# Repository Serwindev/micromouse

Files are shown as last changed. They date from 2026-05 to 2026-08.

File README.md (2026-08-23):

# Project Zacch v1

## About the project

Project Zacch is a full-size micromouse whose aim is to solve the maze autonomously.

The name of the mouse actually comes from Bible (Luke 19:1-10). There was a man called Zacchaeus -- who wanted to see Jesus but because he was short, he couldn't able to see Him. So he climbed a tree to see Jesus.

The dimension of Zacch is 90mm x 127mm (3.54 x 5.00 inches). Compared to other mice out there, it isn't that small. But this is my first-ever hardware project and i needed some more space to work properly.

The Project Zacch v1 is a project made for the event ["Fallout"](https://fallout.hackclub.com/) conducted by [HackClub](https://hackclub.com/).

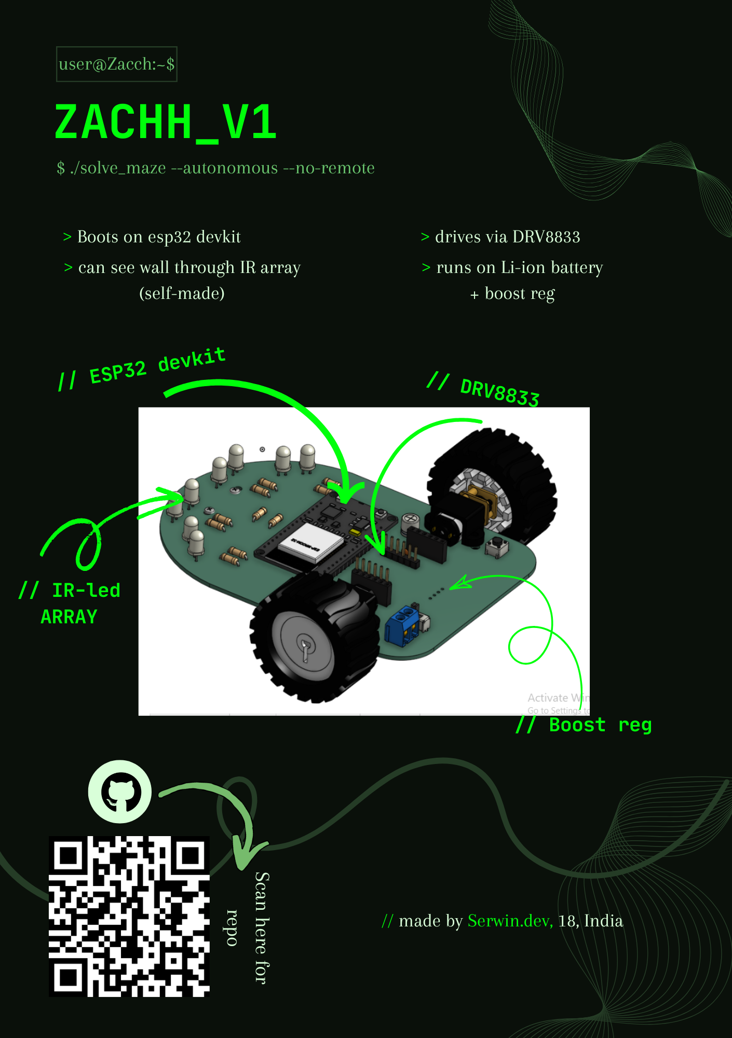
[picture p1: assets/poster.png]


---

## BOM

|sno|product name |description |Quantity |link |unit price |amount |Running total | |
|---|---|---|---|---|---|---|---|---|
|  1| ESP32 | Brain of the Mouse | 1| [link](https://makerbazar.in/products/esp32-wroom-wifi-ble-bluetooth-iot-node-mcu-board?variant=48251049935088) | 445.00| 445.00| 445 | |
|  2| Motor Driver | Bridge between Brain and motor | 1| [link](https://makerbazar.in/products/drv8833-2-channel-1-5a-dc-motor-driver?variant=48341841346800) | 65.00|  65.00| 510 | |
|  3| Motors with encoders| Locomotive device to calculate it's position| 2| [link](https://roboticsdna.in/product/n20-6v-500rpm-micro-metal-gear-motor-with-encoder/ ) | 494 | 988 | 1498 | |
|  4| Infrared Sensors | Eyes to watch out for obstacles | 2| [link](https://makerbazar.in/products/ir-receiver-transistor-led?variant=42847315525872) | 99.00| 198 | 1696 | |
|  5| Battery | To power the mouse | 1| [link](https://robu.in/product/wly603040-600mah-3-7v-single-cell-rechargeable-lipo-battery/?utm_source=chatgpt.com) | 198 | 198 | 1894 | |
|  6| MOSFET | To switch on the IR leds | 2| [link](https://www.digikey.in/en/products/detail/alpha-omega-semiconductor-inc/AO3400A/1855772) | 49.15|  98.30| 1992.3 | |
|  7| Resistors pack | TO limit the current | 1| [link](https://robu.in/product/30-different-valued-metal-film-resistor-assorted-kit-for-diy-electronic-projects-and-experiments/) | 199.00| 199.00| 2191.3 | |
|  8| Wheels | Pair of wheels suitable for N20 | 1| [link](https://dyoraarobotics.in/product/2) | 269 | 269 | 2460.3 | |
|  9| Caster ball | Non-driven wheel to support the mouse | 1| [link](https://makerbazar.in/products/mini-3pi-car-n20-caster-robot-ball-wheel) | 39 |  39 | 2499.3 | |
| 10| Boost converter | To convert low voltage into 5v | 1| [link](https://robocraze.com/products/tps61023-3-7a-5v-output-mini-boost-converter-breakout-board-7semi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) | 87 |  87 | 2586.3 | |
| 11| Switch | To power ON/OFF | 1| [link](https://makerbazar.in/products/3-pin-dip-mini-slide-switch-through-hole-pcb-slide-button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) | 55 |  55 | 2641.3 | |
| 12| Screw terminal | To connect battery | 1| [link](https://makerbazar.in/products/wire-to-board-screw-terminal-connectors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) | 25 |  25 | 2666.3 | |
| 13| Capacitor 47uF | Caps to store energy | 3| [link](https://www.mouser.in/en/ProductDetail/Panasonic/ECA-1HHG470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) | 17.89|  53.67| 2719.97| |
| 14| Capacitor 0.1uF | Caps | 10| [link](https://robu.in/product/rder71h104k0m1h03a-murata-electronics-%C2%B110-50v-100nf-x7r-pluginp5mm-multilayer-ceramic-capacitors-mlcc-leaded-rohs/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) | 16.00| 160 | 2879.97| |
| 15| Female headers | To mount componenets | 3| [link](https://makerbazar.in/products/female-berg-strip-2-54mm-header-pin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)| 8.5 |  25.50| 2905.47| |
| 16| Male headers | To mount components | 2| [link](https://makerbazar.in/products/berg-strip-40-pins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) | 25 |  50 | 2955.47| |
| 17| Tactile switch | To actually make mouse move | 1| [link](https://makerbazar.in/products/small-push-button-switch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) | 20 |  20 | 2975.47| |
| 18  | PCB | Acts as a chassis as well as electrical circuit | 1 | wherever you prefer | 3500 | 3500 | 6475.47 | |
| 19  | 3d print | Mounts for motors | 2 | wherever you prefer (use assets/CAD_design/Motot_mount.stp) | 500 | 1000 | 7475.47 | |

---

## Project Workflow

I have actually journalled everything from Day 1 till the end -- you can find them in the **Devlogs folder**.

#### Research and Development

- On the Day 1, i worked on researching the requirments for the project.
- On further days, i sourced online to find the suitable products and built the BOM (Bill of materials) -- which you can find [here](components/BOM.csv) and also sketched a very rough diagram about the wiring.

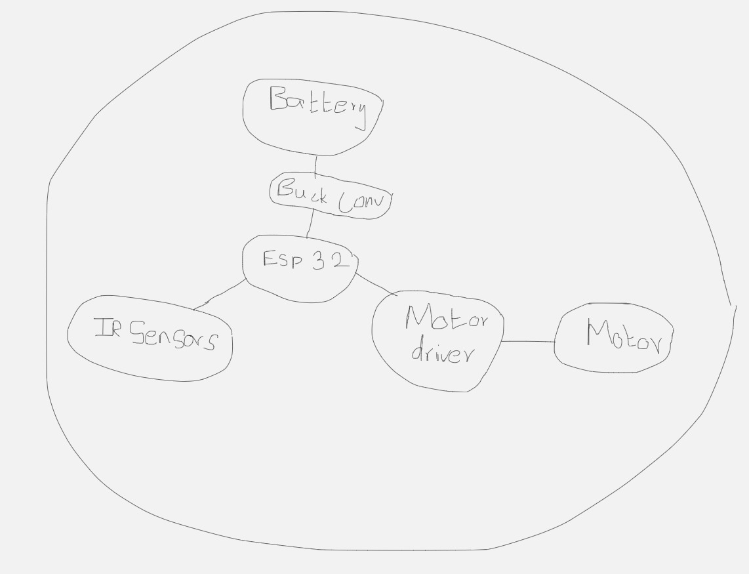
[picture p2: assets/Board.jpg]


---

#### Schematic 

- From day 4, i worked on the Schematic design in Kicad. It's my very first time and i found it kinda hard at first.
- After some several iterations and struggles, with the help of chatGPT, i finished the 1st version of schematic on day 7

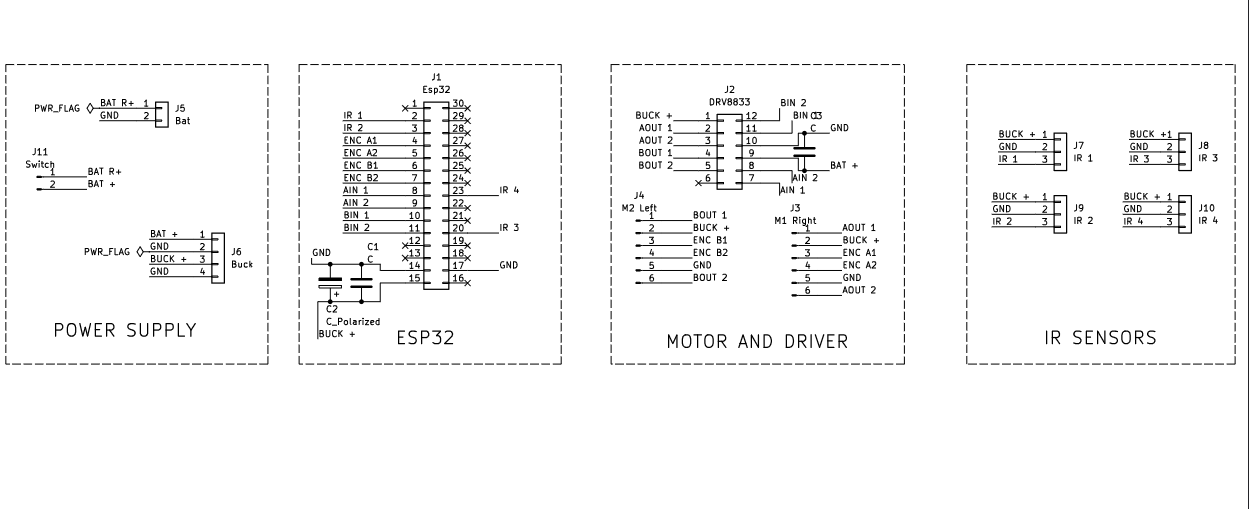
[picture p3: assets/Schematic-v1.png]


---

#### CAD design

- From Day 8, i worked on the CAD design of this project in Tinkercad
- After two days of CAD'ing, i somehow managed to capture the vision in my mind into the Screen. (Spoiler alert: Final result isn't the same as here)

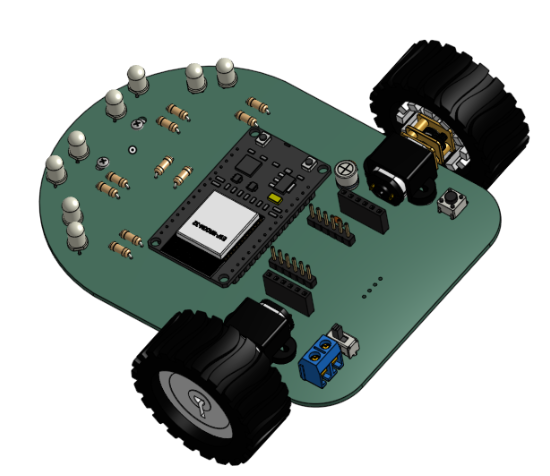
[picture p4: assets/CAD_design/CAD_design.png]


---

#### PCB design

- After the completion of CAD design, i started to add footprints for all the componenets in kicad.
- I found it hard to understand the way footprint works in the consecutive days.
- During these days, i changed the IR sensors - from modules to separate transmiter. (Reason: Because the module provides only True or False output based on whether the obstacle is near or not)
- I completed the whole routing of PCB by the day 20, but then i found that esp32 has been misaligned and needs to be re-aligned.
- After two days of debugging, i completed the PCB (But still, I thought of adding some LED's into the PCB and mounting Pads for caster ball)

##### Front copper

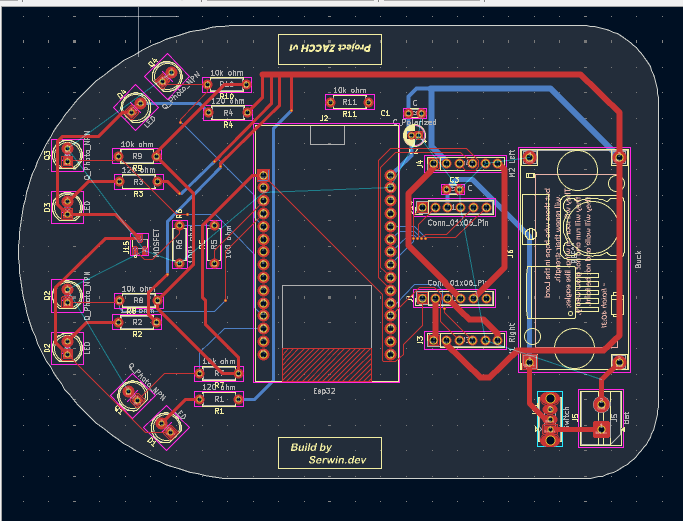
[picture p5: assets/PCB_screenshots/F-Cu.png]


##### Back copper

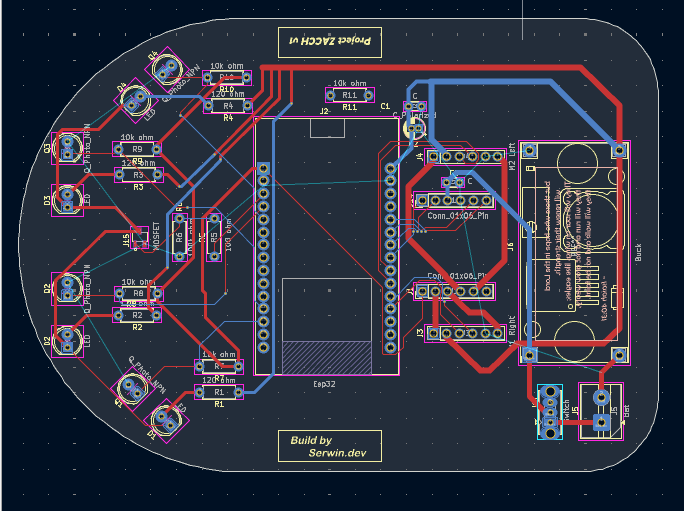
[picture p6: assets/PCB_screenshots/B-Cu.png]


##### Final routing 

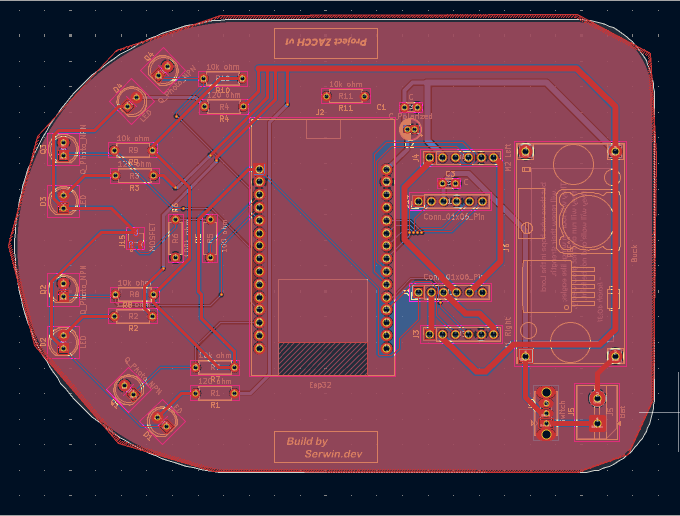
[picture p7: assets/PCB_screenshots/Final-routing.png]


PS: There's an easter egg in the PCB -- if you can find it out and DM me for prizes!! 
Instagram: [@serwin.dev](https://www.instagram.com/serwin.dev)

---

### Features

- Project Zacch uses two driven wheels and a non-driven caster ball for locomotion.
- It uses IR sensors and transmitter to wall sensing mechanism.

---

## How to build?!

- Step 1: Check whether you have all the components
- Step 2: Order PCB and wait -- take some rest
- Step 3: Quickly assemble all the parts
- Step 4: Run firmware and GOOO!!!!

---

### Future works

- Once the build is successful, the firmware of the project will commence.
- Using PID for staying in the center of the line.

---

### Contributors

- [@Serwindev](https://github.com/Serwindev)

---

### Resources

- [Ojasp21/micromouse](https://github.com/Ojasp21/Micromouse/tree/main)
- [Mushak/micromouse](https://github.com/gautam-dev-maker/mushak/tree/main)

---

### Special Credits

- All thanks to HackClub for making this project came into life through [Fallout](https://fallout.hackclub.com/)

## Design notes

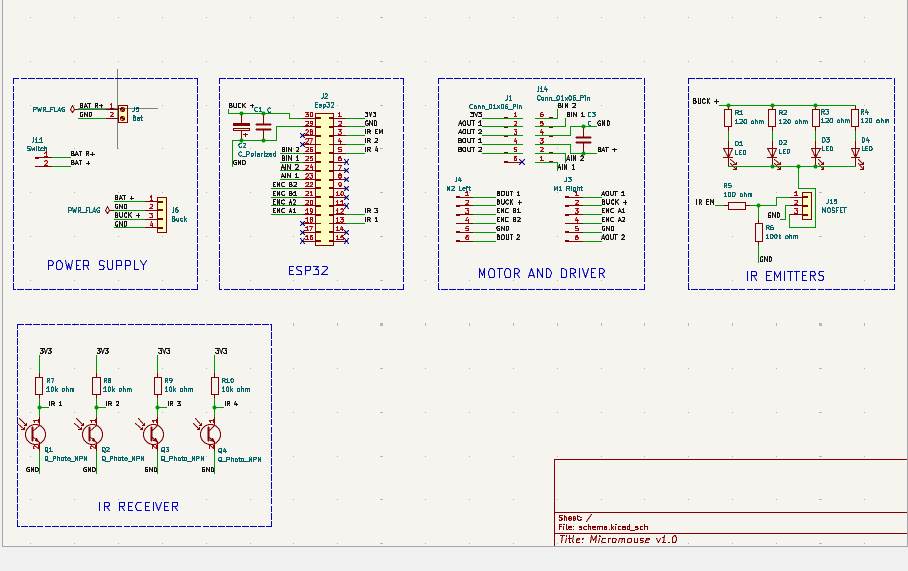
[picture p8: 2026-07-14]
assets/Schematic-v2.png

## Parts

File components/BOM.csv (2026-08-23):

sno | product name | description | Quantity | link | unit price | amount | Running total
1 | ESP32 | Brain of the Mouse | 1 | https://makerbazar.in/products/esp32-wroom-wifi-ble-bluetooth-iot-node-mcu-board?variant=48251049935088 | 445.00 | 445.00 | 445
2 | Motor Driver | Bridge between Brain and motor | 1 | https://makerbazar.in/products/drv8833-2-channel-1-5a-dc-motor-driver?variant=48341841346800 | 65.00 | 65.00 | 510
3 | Motors with encoders | Locomotive device to calculate it's position | 2 | https://roboticsdna.in/product/n20-6v-500rpm-micro-metal-gear-motor-with-encoder/ | 494 | 988 | 1498
4 | Infrared Sensors | Eyes to watch out for obstacles | 2 | https://makerbazar.in/products/ir-receiver-transistor-led?variant=42847315525872 | 99.00 | 198 | 1696
5 | Battery | To power the mouse | 1 | https://robu.in/product/wly603040-600mah-3-7v-single-cell-rechargeable-lipo-battery/ | 198 | 198 | 1894
6 | MOSFET | To switch on the IR leds | 2 | https://www.digikey.in/en/products/detail/alpha-omega-semiconductor-inc/AO3400A/1855772 | 49.15 | 98.30 | 1992.3
7 | Resistors pack | TO limit the current | 1 | https://robu.in/product/30-different-valued-metal-film-resistor-assorted-kit-for-diy-electronic-projects-and-experiments/ | 199.00 | 199.00 | 2191.3
8 | Wheels | Pair of wheels suitable for N20 | 1 | https://dyoraarobotics.in/product/2 | 269 | 269 | 2460.3
9 | Caster ball | Non-driven wheel to support the mouse | 1 | https://makerbazar.in/products/mini-3pi-car-n20-caster-robot-ball-wheel | 39 | 39 | 2499.3
10 | Boost converter | To convert low voltage into 5v | 1 | https://robocraze.com/products/tps61023-3-7a-5v-output-mini-boost-converter-breakout-board-7semi | 87 | 87 | 2586.3
11 | Switch | To power ON/OFF | 1 | https://makerbazar.in/products/3-pin-dip-mini-slide-switch-through-hole-pcb-slide-button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 | 55 | 55 | 2641.3
12 | Screw terminal | To connect battery | 1 | https://makerbazar.in/products/wire-to-board-screw-terminal-connectors?variant=48816549658864 | 25 | 25 | 2666.3
13 | Capacitor 47uF | Caps to store energy | 3 | https://www.mouser.in/en/ProductDetail/Panasonic/ECA-1HHG470 | 17.89 | 53.67 | 2719.97
14 | Capacitor 0.1uF | Caps | 10 | https://robu.in/product/rder71h104k0m1h03a-murata-electronics-%C2%B110-50v-100nf-x7r-pluginp5mm-multilayer-ceramic-capacitors-mlcc-leaded-rohs/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 | 16.00 | 160 | 2879.97
15 | Female headers | To mount componenets | 3 | https://makerbazar.in/products/female-berg-strip-2-54mm-header-pin?variant=46822716735728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 | 8.5 | 25.50 | 2905.47
16 | Male headers | To mount components | 2 | https://makerbazar.in/products/berg-strip-40-pins?variant=49811925532912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 | 25 | 50 | 2955.47
17 | Tactile switch | To actually make mouse move | 1 | https://makerbazar.in/products/small-push-button-switch | 20 | 20 | 2975.47
18 | PCB | Acts as a chassis as well as electrical circuit | 1 | wherever you prefer | 3500 | 3500 | 6475.47
19 | 3d print | Mounts for motors | 2 | wherever you prefer (use assets/CAD_design/Motot_mount.stp) | 500 | 1000 | 7475.47

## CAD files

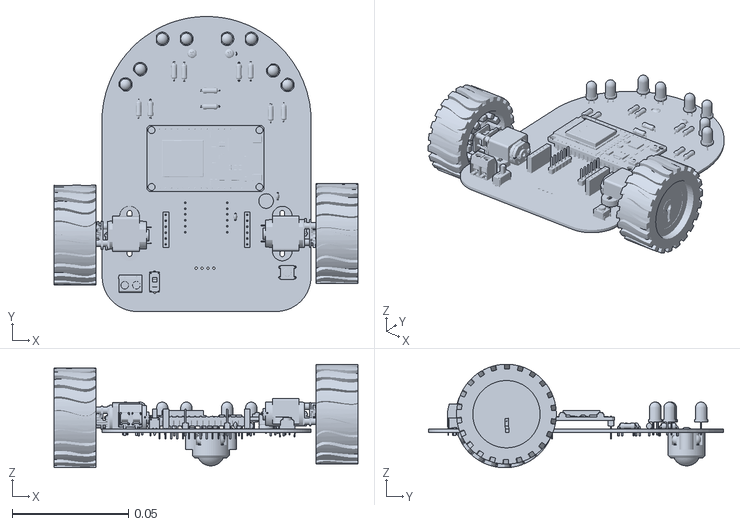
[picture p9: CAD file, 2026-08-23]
assets/CAD_design/Final-CAD.stl
0.131 x 0.127 x 0.0446

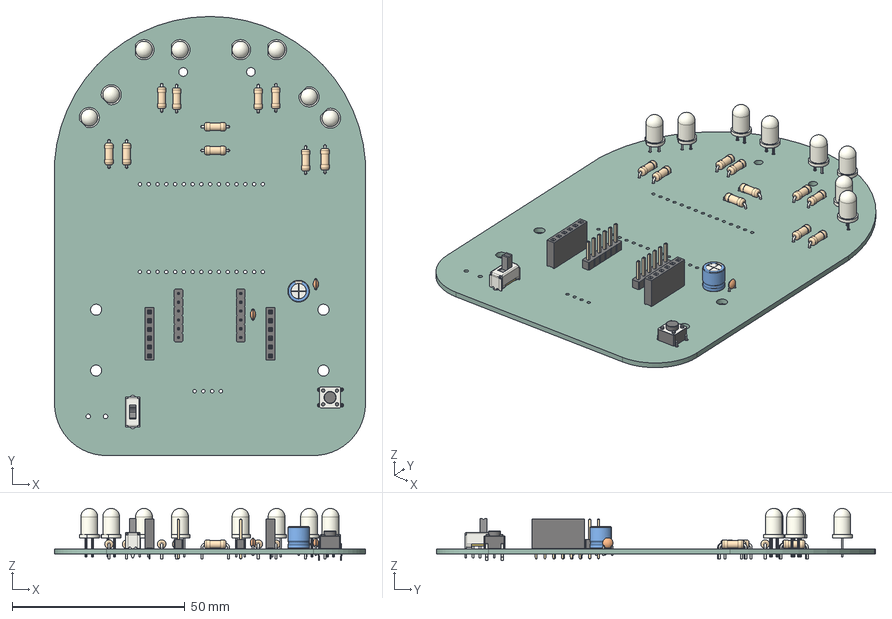
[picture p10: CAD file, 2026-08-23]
kiCad/schema/model-1.step
90.0 x 127.1 x 15.1 mm
R_Axial_DIN0207_L63mm_D25mm_P762mm_Horizontal x 10
CP_Radial_D63mm_P250mm
PinHeader_1x06_P254mm_Vertical x 2
LED_D5.0mm_Clear x 8
C_Disc_D30mm_W16mm_P250mm x 2
PinSocket_1x06_P2.54mm_Vertical x 2
SW_Slide_SPDT_Straight_CK_OS102011MS2Q
SW_PUSH_6mm_h5mm
schema_PCB

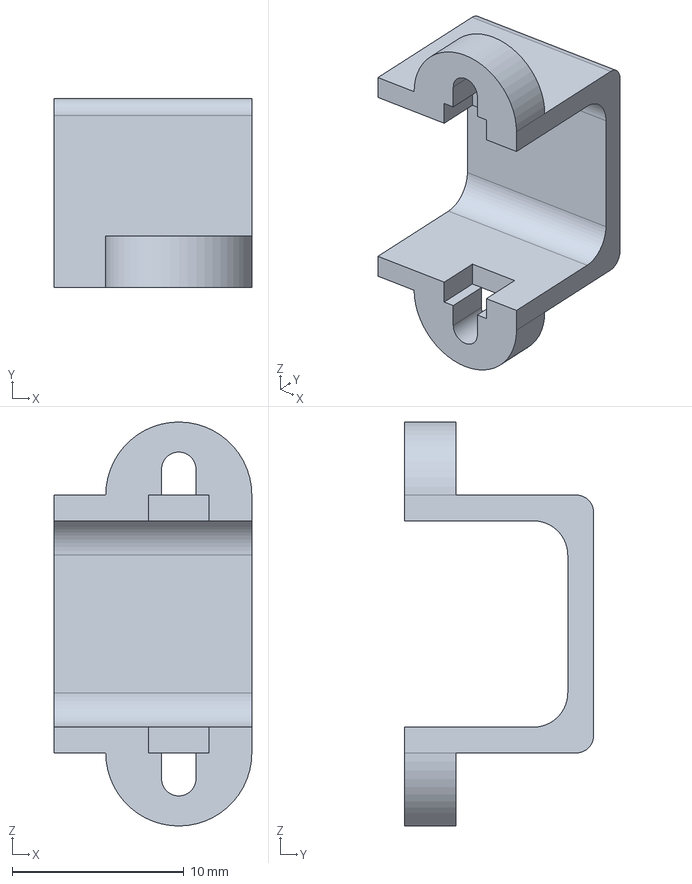
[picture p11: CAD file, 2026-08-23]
assets/CAD_design/Motot_mount.stp
11.5 x 11.0 x 23.5 mm

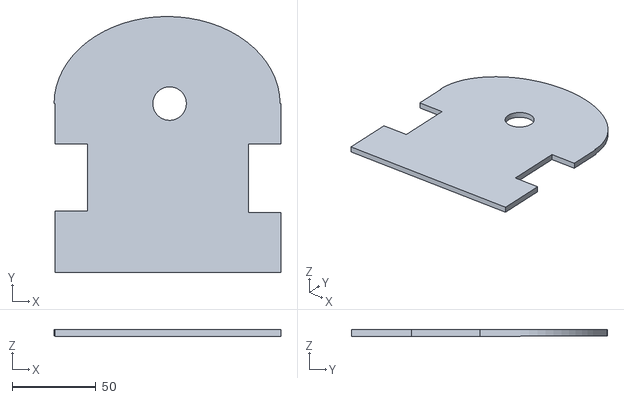
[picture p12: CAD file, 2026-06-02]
assets/CAD_design/Micromouse.stl
135.5 x 152.9 x 4.00

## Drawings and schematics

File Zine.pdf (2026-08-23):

# ZACHH

_

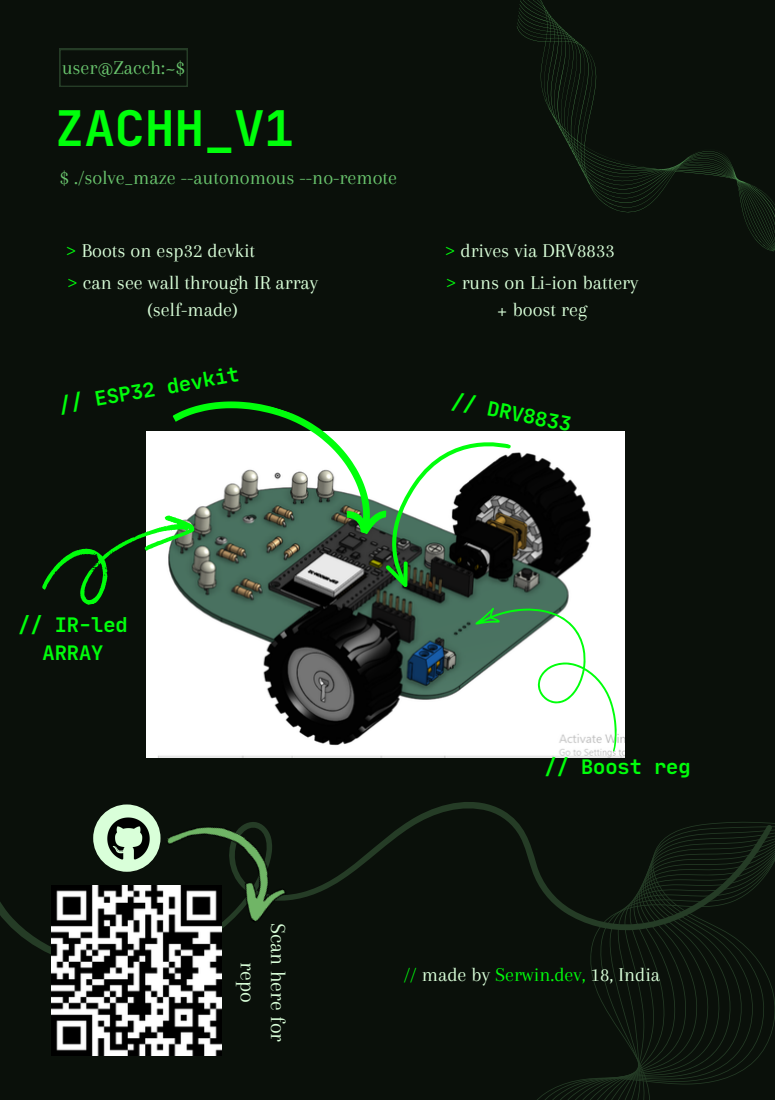
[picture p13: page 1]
user@Zacch:~$; (self-made); // Boost reg; // ESP32 devkit; // IR-led ARRAY; // DRV8833

$ ./solve_maze --autonomous --no-remote

> Boots on esp32 devkit
> can see wall through IR array

> drives via DRV8833
> runs on Li-ion battery
+ boost reg

// made by Serwin.dev, 18, India

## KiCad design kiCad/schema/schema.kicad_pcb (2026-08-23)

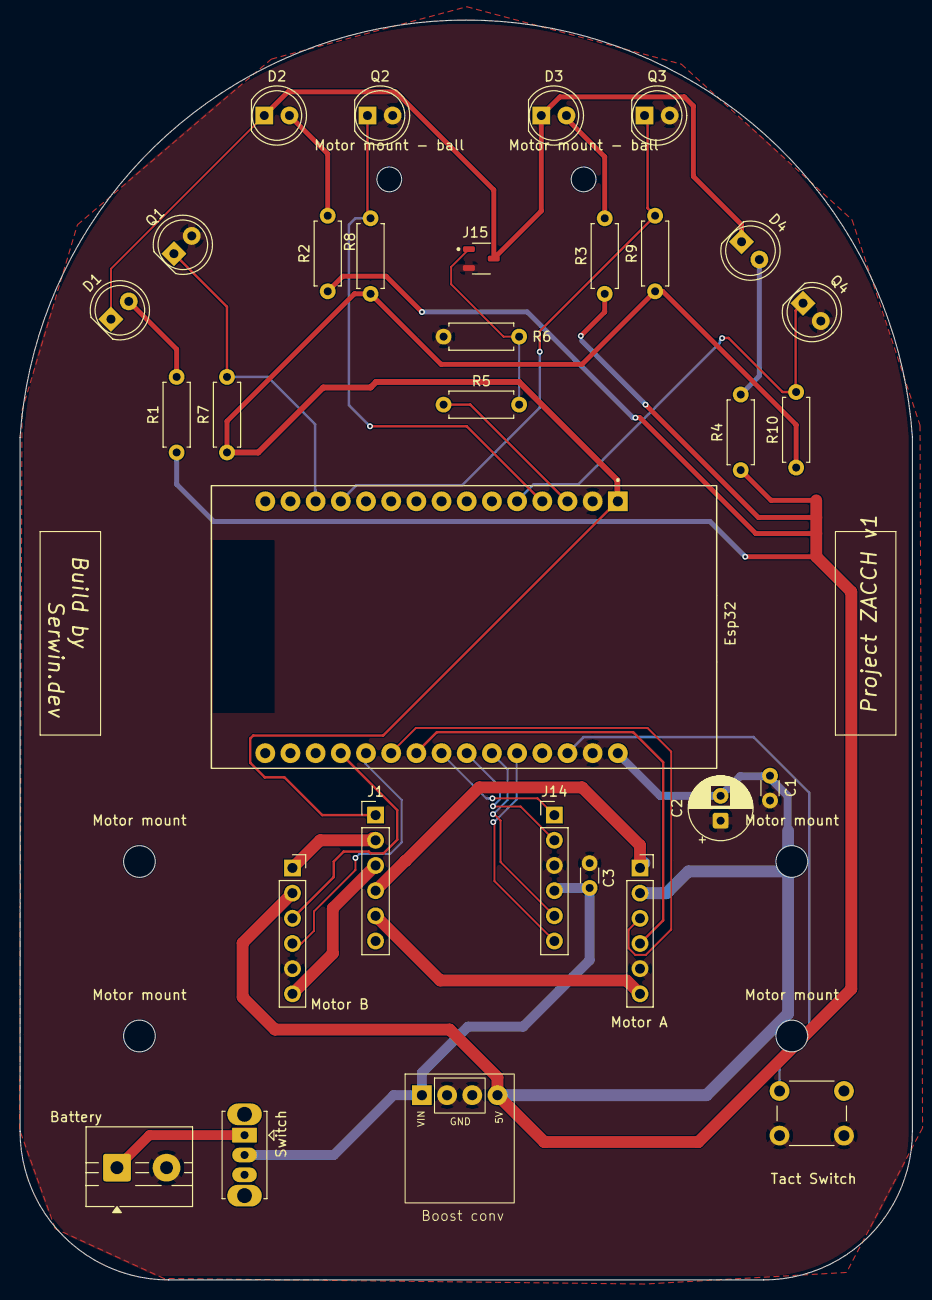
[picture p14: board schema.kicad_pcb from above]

Board: 2 copper layers, 90.0 x 127.1 mm, 37 parts (0 on the bottom side), 29 nets.

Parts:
Battery: Bat; TerminalBlock_MaiXu_MX126-5.0-02P_1x02_P5.00mm
Boost conv: BOOST; TPS61023
C1, C3: C 0.1; C_Disc_D3.0mm_W1.6mm_P2.50mm
C2: C_Polarized 47; CP_Radial_D6.3mm_P2.50mm
D1, D2, D3, D4: LED; LED_D5.0mm_Clear
Esp32: Esp32; MODULE_ESP32_DEVKIT_V1
J1: DRV8833; PinHeader_1x06_P2.54mm_Vertical
J14: GND; PinHeader_1x06_P2.54mm_Vertical
J15: MOSFET; SOT95P280X125-3N
Motor A: M2 Left; PinSocket_1x06_P2.54mm_Vertical
Motor B: M1 Right; PinSocket_1x06_P2.54mm_Vertical
Motor mount: MountingHole_3.2mm_M3
Motor mount - ball: MountingHole_2.5mm
Motor mount - ball#2: MountingHole_2.5mm
Motor mount#2, Motor mount#3, Motor mount#4: MountingHole_3.2mm_M3
Q1, Q2, Q3, Q4: Q_Photo_NPN; LED_D5.0mm_Clear
R1, R2, R3, R4: 120 ohm; R_Axial_DIN0207_L6.3mm_D2.5mm_P7.62mm_Horizontal
R5: 100 ohm; R_Axial_DIN0207_L6.3mm_D2.5mm_P7.62mm_Horizontal
R6: 100k ohm; R_Axial_DIN0207_L6.3mm_D2.5mm_P7.62mm_Horizontal
R7, R8, R9, R10: 10k ohm; R_Axial_DIN0207_L6.3mm_D2.5mm_P7.62mm_Horizontal
Switch: Switch; SW_Slide_SPDT_Straight_CK_OS102011MS2Q
Tact Switch: Tact Switch; SW_PUSH_6mm_H5mm

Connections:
/3V3: Esp32.1, J1.1, R7.1, R8.1, R9.1, R10.1
/AIN 1: Esp32.23, J14.1
/AIN 2: Esp32.24, J14.2
/AOUT 1: J1.2, Motor B.1
/AOUT 2: J1.3, Motor B.6
/BAT +: Boost conv.1, C3.1, J14.4, Switch.2
/BAT R+: Battery.1, Switch.1
/BIN 1: Esp32.25, J14.5
/BIN 2: Esp32.26, J14.6
/BOOST +: Boost conv.4, C1.1, C2.2, Esp32.30, Motor A.2, Motor B.2, R1.1, R2.1, R3.1, R4.1
/BOUT 1: J1.4, Motor A.1
/BOUT 2: J1.5, Motor A.6
/ENC A1: Esp32.19, Motor B.3
/ENC A2: Esp32.20, Motor B.4
/ENC B1: Esp32.21, Motor A.3
/ENC B2: Esp32.22, Motor A.4
/GND: Battery.2, Boost conv.2, Boost conv.3, C1.2, C2.1, C3.2, Esp32.2, Esp32.29, J14.3, J15.2, Motor A.5, Motor B.5, Q1.2 (E), Q2.2 (E), Q3.2 (E), Q4.2 (E), R6.1, Tact Switch.2
/IR 1: Esp32.13, Q1.1 (C), R7.2
/IR 2: Esp32.4, Q2.1 (C), R8.2
/IR 3: Esp32.12, Q3.1 (C), R9.2
/IR 4: Esp32.5, Q4.1 (C), R10.2
/IR EM: Esp32.3, R5.1
/SW PIN: Esp32.28, Tact Switch.1
unnamed: D1.2 (A), R1.2
unnamed: D1.1 (K), D2.1 (K), D3.1 (K), D4.1 (K), J15.3
unnamed: D2.2 (A), R2.2
unnamed: D3.2 (A), R3.2
unnamed: D4.2 (A), R4.2
unnamed: J15.1, R5.2, R6.2

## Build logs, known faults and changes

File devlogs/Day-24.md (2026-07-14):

# Day 24 - Devlog

Zacch v1 is about to come alive

## Devlog

Yesterday, i have added the tactile button..!!

Everything is fine now!! -- Gotta see pcb once again and finish the work

Since, i have boostedt the voltage, the IR led's resistors need to be changed (Just the values)

Then, i added mounting pad to mount motors in place.

So far, so good. 

Then, i remembered something -- i got to work on firmware

I did a simple firmware -- idk how to write them 

How can i write without executing??!! 

I'm submiting the project and then, will work on the firmware

## Work Done

- Did polishing works
- Wrote a simple firmware
- Gonna work on Zine and submit the project

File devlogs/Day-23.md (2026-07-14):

# Day 23 

Zacch v1 is almost finished

I have finished the README, also did some progress in Zine (Didn't recorded it -- IDK whether i could do that) and also, i did finished the BOM.csv

## Devlog

But, after these, i found that my battery doesn't require any buck converter at all.. Instead, it needs boost converter

But the boost converter doesn't have any footprint online, i'm gonna create one by myself.

I did created a footprint -- yeaa!!! MY first ever footprint.

Then, i found that there's a lot of space and i wanted to add a tactile button -- cuz, why not?

## Work Done

- Added Tactile button
- Removed buck converter and replaced it with boost converter

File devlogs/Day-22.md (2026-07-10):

# Day 22

Hopefully, i will finish the PCB by adding the LED setup

---

## Devlog

At first, i solved the GND error which occured yesterday..!!

After that, i removed the mounting pads from the esp32 footprint..!!

I want caster ball to provide stability and mount them in the PCB itself -- so first i have to finalise the wheel and caster ball

I have found the parts and noted them in the BOM -- still i got a lot of works to do!!

I'm gonna work on README now and then on the zine

## Work Done

- fix: GND error
- Sourced wheels and caster ball
- Wrote a really good README

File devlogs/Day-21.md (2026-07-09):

# Day 21 

Recurring errors of same kind

---

## Devlog

Yesterday, i found an error and i thought that i have solved it -- but here i am, with the same error... I haven't solved it yesterday :sob:

Now, i'm asking GPT for a better solution but i'm understanding NONE

I'm now trying to create my own solution

I found the solution but still i got re-trace everything :sob:

I will comeback after 30 mins of re-tracing lol

The esp32 error was gone -- i realigned everything but

Now the GND fill isn't getting connected - i got to work on it tmrw

---

## Work Done:

- Found that the esp32 error still exists and tried to solve it.
- Rectifed the mis-alignment error
- Found a new error now (GND isn't getting filled correctly)

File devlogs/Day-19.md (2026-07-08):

# Day 19

So, we are almost there -- Have to do PCB route for IR leds and receivers today

## Devlog

Let's open kicad..!! (It's loading...)

Note: I'm using chatGPT to determine the width of the copper traces

I did something now -- i took one correction from Esp32 (3v3) and connected it into the first led -- then took route from first led to the next and so on..

IDK whether this works -- I have asked GPT about this 

I did routed the IR led's with some difficulty -- cuz, there's no space 

Therfore i'm thinking to switch the IR led into the opposite of original connection in schematic

I have changed the GPIO pins for the IR leds -- to align it near to the IR led side..!!

NOW, i connected every IR leds to the esp32 -- still, i have to connect the MOSFET and resistors to the Receivers

So, I adjusted the led into a symmetric position -- with 5mm distance between IR led and emitters

I did all the routing and now, i'm gonna export and send it in discord, slack and chatGPT for verification

When i first ran DRC, i found almost 15 errors and then i solved almost everything

But now, There is an error called "Thermal relief connection.."

I got to google it and solve it soon -- I set the clearance of Ground plane into 0.25mm and the error gets solved!!

Now, i'm working on the silkscreen part -- IDK whether i would add a led..!! Maybe not

I'm planning to name the micromouse and print it in Silkscreen -- Maybe, Project ZACCH v1

Also, i'm planning to write Isaiah 40:31 on the back of the micromouse

After that, i have added my name and gonna finish the whole thing!!

After finishing this, i went to see the prices on online for ordering..!!

I found that the cost ranges from Rs 2k to Rs 2.5k 

That's all for today

## Work Done

- Finished the whole PCB design
- Sent the design in discord and slack for review and feedback
- Exported it into gerber and enquired the price for PCB manufacture

X7R dielectric

V-rated electrolytic capacitors

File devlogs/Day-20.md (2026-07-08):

# Day 20

I'm thinking to add some SMD leds into the board 

## Todo

- Add LEDs into the Schematic
- Add LEDs on the back of the board and route it

## Devlog

So, let's decide something -- I need the Led to turn on when the switch is ON and turn off when it's off

I'm planning to use PLCC -- since it is kinda big (Easy to solder, hehehe)

SOMETHING HUGE!!! 

I found that i have plotted the esp32 pins in the wrong direction :sob:

Have to change them... BRUHHHHHHHHH

Only after that, i will move to the LED again

I got an idea -- why not just rotate the component in the schematic and update PCB

Yoo!! I updated the PCB and rectifed the Esp32 error

But i haven't added the leds yet..!!

---

## WorkDone

- Expected to finish led but found a new error -- Esp32 mis-pin alignment
- Solved the esp32 pins misalignment

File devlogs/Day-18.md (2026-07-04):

# Day 18

We got to work on the traces/routing real quick and finish the project within 3-4 days

## Todo

- Routing for IR led and motors

## Devlog

Actually, for routing i am using chatGPT to verify my routes and determining the thickness (I really got no idea -- since it was my first time)

But i tried to ask these doubts to real person -- so i msged in discord

Lemme read some articles in the meantime

I did asked doubts in discord, slack and also went through that [github repo](https://github.com/Ojasp21/Micromouse/tree/main)

So, i searched for answers and found none..

Then, i found someone -- he helped me to understand the way schematic should work and also taught me about Ground plane (Copper pour in PCB)

Bruh, my cats are doing something...!!

Somehow, i managed to rectify the things that my cats caused -- lol

I learned a lot about kicad -- about K, X, V hotkeys

Also, i finished 60% of PCB and it's so cool

But, i feel sleepy now and will continue this tmrw

Seeya

## Work Done

- PCB routing - 60% done
- Communicated with a stranger and learnt about kicad's PWR_FLAG

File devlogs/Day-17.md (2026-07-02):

# Day 17

We will start routing the components today

## Devlog

I changed the footprints for the motor mounting -- from male to female headers

I started to do routing then and found a lot of errors in schematic -- hehe, i rectifed them

For routing, i used chatGPT to explain the copper traces width

While doing so, i had a doubt -- so i asked GPT and i got new idea to route my PCB

I did some small connections but then i got a call -- i was so focused on the call that i forgot to stop the recording lol 

## Work done

- PCB layout and components arrangement done
- Started routing for components -- Done for BUCK, Battery and DRV8833

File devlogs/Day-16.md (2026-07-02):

# Day 16

So, today i would work more on the layout of the components and then start routing

## Devlog

Every devlog starts with kicad crashing 🤣 -- Maybe i am not being 

I did some changes in the Esp32 and DRV8833 placements

After searching for footprints for the esp32 -- i found that i was wrong

Yup, i mapped the labels wrongly and now i am correcting everything...

After that, i sent the final layout to chatGPT and it's feedbacks are wrong btw 🤣

That's all for today -- will start routing after making some layout changes tmrw

## Work done

- Placed all the components at the respective places
- Found that footprint of esp32 is wrong and changed everything

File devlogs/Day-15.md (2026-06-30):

# Day 15

I'm thinking of completing this project within 5 days

So, today i'm gonna work on the pcb layout -- after it's done, i will maybe add some SMD leds

## Devlog

Opening kicad... Already imported everything into the PCB..!!

Also, the dimensions i am going with is -- btw, i used chatGPT for this -- I would go with 9x10 cm

Drawing just the layout itself is very hard and time-consuming..!!

Kicad is always crashing whenever i tried to open it

So, i got some ideas for layout after visiting other micromouse repos

I made the layout finally -- also i added the components into it and found that there's plenty of room to occupy..!!

Tmrw, i have to drill holes for caster wheel and layout again

That's all for today

## Work done

- Found how to actually layout the pcb
- Arranged all the components into the pcb as rough

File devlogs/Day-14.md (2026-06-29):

# Day 14

Today, we are gonna ad footprints for the capacitors and resistors
Then, we would check for anyother improvements for the schematic (like some leds..)

## Devlog

Opening kicad and adding footprints rn

I added footprints for everything -- Also i found that MOSFET i am using is Surface mounted -- but i made it let it be... Cuz, let's practice that too!!

Then, I sourced the resistors for the whole project -- I used chatGPT to verify the products and finally, i imported everything into PCB

From tommorow, i am gonna work on PCB :on_fire:

I'm so glad..!! But still, i would maybe add few leds -- SMD (Why not?!)

## Work done

- Added footprints for resistors, MOSFET, capacitors
- Imported everything into PCB with no errors
- Everything is ready to work on PCB next

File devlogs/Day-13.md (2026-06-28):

# Day 13

We will move forward into adding footprints for other components

## Devlog

I sourced footprints for buck converter from online

Found a THT footprint at [here](https://grabcad.com/library/lm2596-module-for-kicad-1)

Then, i quickly set it up in kicad and then i went to check the connections for our new IR emitter and receiver

I did some rough schematic for the connection and sent it to chatGPT for debugging

Then i quickly did the schematic for phototransistor too -- **Happiee, Happie, Happy**

I also added the footprints for IR leds and placed them in PCB

That's all for today

## Work Done

- Added IR emitter and receiver schematics
- Added footprints for them
- Placed them in PCB

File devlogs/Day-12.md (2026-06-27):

# Day 12

Resuming the project after a long break

## Todo
- Visit the schematics -- maybe add decoupling capacitors in IR sensors
- Implement footprints

## Devlog

Bruh.. Kicad crashes again

Working now -- So, i visited the repos and found they are using IR emitter and transmitter separately -- but i'm gonna use IR sensors module.

Finding footprints are really hard -- tbh

But i found footprints for Switch, battery and much more..!!

I added new IR sensors -- removing the module and going with individual emitter and receiver for better performance

That's all for today!!

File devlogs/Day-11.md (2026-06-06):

# Day 11

I haven't made any progress for the past few days 
I'm just gonna make little progress today -- Something is better than nothing

## Todo

- Cad design ✅
- Assign footprints

## Devlog

I tried assigning the footprints but it isn't loading well..!!
So, i moved to finding the footprints from internet

I added the Capacitor's footprints and also pins for motors -- it is good

Then i moved to frame the PCB -- rectangle mounted by a circle -- micrmouse looking..!!

Then, I got headache and i'm shutting down..

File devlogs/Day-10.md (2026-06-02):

# Day 10

## Todo

Let's complete the CAD design
- Motors
- Motor driver
- Caster ball
- battery

## Devlog

I started by adding the motors into the 3d design.

I added both motors and wheels..!!

After that, i added the caster wheel -- i'm not satisfied with that but anyway i added it.

I exported the design without adding battery -- i hope it's enough for now and we now have to move to PCB design.

I added the footprint for esp32 holders -- i changed the connectors too.>!!

Tried adding capacitors but didn't.

That's one hour already!!

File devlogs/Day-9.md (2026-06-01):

# Day 9

Heyy!! Today we are diving into the CAD design -- try to finish it today

## Todo

- Add gaps for motors
- Decide how many wheels
- Add some rough models for all modules

## Devlog

I started by reducing the height of the plane -- then gonna decide whether 2 or 4 wheels...!!

Mouse got only two legs, right?!! -- I would go with 2 wheels then lol

2 wheels provide easy turning around the corners but 4 wheels introduce friction and it's hard to turn.

I did made some cuts for wheel.

I added wheels on both side and also reduced size for esp32.!!

I found that tinkercad had built-in hardware modules..

So, i quickly added Esp32 and IR sensors..!

It's kinda good now but i do have doubt in IR sensors

That's one hour already!!

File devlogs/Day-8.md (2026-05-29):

# Day 8

Heyy!! Yesterday, we completed the schematic diagram..!!

And today, i'm gonna refine it by adding capacitors, footprints and much more..

## ToDo

- Work on the refinement
- Add footprints and understand it's usage

## Devlog

Let's dive straight into the refinement process.

I went through the micromouse project -- done by someone in github and got some ideas for PCB design..!!

But now i feel like staying behind..!! But i am gonna try again -- improve schematics

I'm changing my mind -- I am gonna do CAD next and simultaneously improve the schematics and adding footprints.

I spent time, searching through resources and found some GOLD!!! 

- [See this](https://github.com/Ojasp21/Micromouse/tree/main)
- [Micromouse from India](https://github.com/gautam-dev-maker/mushak/tree/main)

I did the design -- Yup just the layout in the Tinkercad..!! AutoCad is kinda expensive btw

That's one hour already!!

Seeya

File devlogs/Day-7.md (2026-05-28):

# Day 7

## Todo

We got to finish up the schematics today -- learn abt VCC and GND to finish the schematics.

## Devlog

First, i started by connecting the PWR_FLAG with VCC and GND.

I learned that i should be using two different power rail for the project

Also, i understood that i shouldn't be spamming the VCC and GND -- so, i removed the VCC and instead i used the BAT + and BUCK + -- which is good.

Man, I ran ERC and found zero errors

We finished the schematic :sob: -- It's really a good journey..!! Yup, we did it.

I have sent it for feedback -- we would jump into PCB tmrw..!!

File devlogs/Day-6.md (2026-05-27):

# Day 6

## ToDo: 

Today, we got to finish the whole schematic diagram -- and do some debug

--- 

## Devlog

Guys, I did all the connections but i wasn't sure whether it's right..!!

Therfore, i shared with ChatGPT and it says, the connections aren't sure.

So, i switched to Perplexity and then I told it clearly -- i just had two pins not connected.

Also, i read some articles about GND and micromouse -- like there's a lot to go!!

After that, i did research to learn about PWR flag in kicad.

So far, so good -- hopefully

Man - it's kinda frustrating -- PWR_FLAG, GND, VCC :ahhhhh:

That's one hour already!! See ya

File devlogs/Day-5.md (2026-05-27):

# Day 5

Today, i started with the schematic design which was left over yesterday.

I removed the wires and replaced them using labels.

I really loved today's progress -- schematic diagram is making some sense now.

But i did made some mistakes -- wiring without seeing the pinout diagram

So that, i was in need of doing the same labeling again.

But still, i didn't able to complete the whole schematic..!!

See you, tmrw.

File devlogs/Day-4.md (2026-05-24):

# Day 4 

Today, I drew the components connection in the [whiteboard](../assets/Board.jpg)

So far, we have decided the components and also drew up the connections.

Nect we move to the Schematic design -- i really don't have any idea but let's learn.

I'm using kicad for the schematic design..!!

First, i will import the esp32 and then start connecting the motor driver and motors.

man, finding a esp32 in kicad is very hard -- so i switched to add just 15 pins on both sides.

While doing schematic, i'm not starting everything from scratch, i just need the pins -- 1-30 for Esp and 1-12 for DRV8833 

So, i setted up the pins and now connecting them..!! Excitinggg

Next, we gotta join the motors into the circuit -- We aren't gonna fix the motor into the pcb 

So, i just need the 6 pins again.

The schematic is kinda sucks -- but i will rectify it tomorrow..!!

That's 1 hour already!!

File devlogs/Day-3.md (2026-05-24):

# Day-3 -- Doing some MATH

Actually, Today -- i'm gonna focus on calculating some math (FOR BATTERY!!!!) 

Todo:
- Find battery specifications and source it.
- Create a rough sketch for the wiring..!!

This ensures about the components and it's connections

Esp-32 internally works with 3.3v -- but we can provide power by plugging 5v USB cable too.
- Input: 3.3v or 5v
- Output: 3.3v or 5v

Which is kinda good -- because it works with low voltage.

Our next important part is motor driver -- motor driver helps to communicate with the MicroProcessor and motor
- Input: Ranges from 2.7v to 10.8v (This works fine with Esp's output)
- Output: Peak - 1.5A (Still some doubts)

After that, we need to look for the motors
- Input: Ranges from 3v to 12v  

This still comes under Day - 3

I'm going to create a To-Do list on what to do -- 
1. Draw a simple schematic diagram
2. While doing so, prepare the products and source it.
3. Move into final schematic diagram.

The project contains a battery, DC motors with Encoders, Motor driver, ESP 32, Infrared sensors.

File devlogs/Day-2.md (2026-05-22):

# Day 2 - Sourcing parts

I thought, sourcing parts would be fun and easy but it's just made me frustrating..!!
Nevertheless, i sourced products for ESP32, Motor driver and Motors 

When it come to Battery, i came to learn about a new term called "Discharge Ratio"

it's so interesting -- the formula is simple too
Discharge rate = discharge ratio x Battery capacity

The motor i am choosing for this project is N20 12V motors with Encoders..!! 

It will cost current around 0.9A -- PEAK current.
I'm using two and so, the highest current will be around 2+A (Including the ESP32, other components)

Therefore, the battery should be able to discharge this current safely

I found a 3.7V 150mAh LiPo Rechargeable Battery -- which has a discharge ratio of 0.2C and the battery capacity is 150mAh

By using the formula, we can calculate the discharge rate and which is 3A >> 2A

Hopefully, i will be able to use this battery -- Hopefully, I have to research more about this and finalize my decision.

Shitt -- ChatGPT just told me that i have to convert mAh -> Ah 
If i did according to that, then the motors can barely move -- because the discharge rate is just 0.3A

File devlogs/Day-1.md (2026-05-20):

## What is a micromouse?!

- Micromouse is an autonomous robot designed to navigate through the maze with absolutely no help from anyone.

## Why micromouse?!

- It’s fascinating, isn’t it?!

## Ingredients:

- ESP32 (Brain)
- Motor driver (To communicate with Brain and motors)
- Infrared sensors x4 (Obstacle)
- DC motors with Encoders (ofc, To move)

### ESP32

I found out that ESP32 would be cheap and cool to use — it is very beginner friendly too.

### Motor driver

Motor drivers are something that translates low voltage (From arduino) to high voltage (Necessary for motors) —> It makes the motor to be operated by the commands of arduino.

### Sensors

I’m gonna use three sensors — front-middle, front-right and front-left — to detect the walls and communicate it with the microprocessor.

### Motors with Encoders

This is the locomotive part in the micromouse — it will contain the encoder within itself. Encoders are necessary to know the exact position of our mouse in the maze.

These are the main necessary parts — but still a lot to be added (Chassis, Buck converter, etc…) 

Let’s move to the next part — which is requirements..!!

## Requirements

Let's decide what our Micromouse should do

- It should autonomously move to the goal -- center of the maze.
- It should be able to maintain center position
- It should be able to scan for obstacles.
- It should be able to track its current position.
- It should be able to calculate the best path (Using floodfill algo)

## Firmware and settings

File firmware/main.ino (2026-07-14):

const int buttonPin = 4;
const int irFront = 34;

void setup() {

  pinMode(buttonPin, INPUT_PULLUP);

  pinMode(18, OUTPUT);
  pinMode(19, OUTPUT);
  pinMode(26, OUTPUT);
  pinMode(27, OUTPUT);

  Serial.begin(115200);
}

void loop() {

  while (digitalRead(buttonPin) == HIGH) {
    delay(10);
  }

  delay(200);
}

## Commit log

2026-05-20 BOM added
    [BOM.csv]
2026-05-22 Day-2 completed
    [BOM.csv]
2026-05-24 Day 4 -- Schematic design
    [schema.kicad_pcb, schema.kicad_sch]
2026-05-27 Day 4
    [schema.kicad_sch]
2026-05-27 Day 6 - Schematics
    [schema.kicad_sch]
2026-05-28 Day 7 - Schematics finished
    [schema.kicad_sch]
2026-05-29 Day 8 - Research, CAD design
    [schema.kicad_pcb, schema.kicad_sch]
2026-06-01 Day 9 - CAD design
    [Micromouse.stl]
2026-06-02 Day 10 - CAD design, PCB design started
    [Micromouse.stl, schema.kicad_pcb, schema.kicad_sch]
2026-06-06 Day 11 -- PCB, footprints, headache
    [schema.kicad_pcb, schema.kicad_sch]
2026-06-27 Day 12 -- Resuming the project
    [BOM.csv, schema.kicad_pcb, schema.kicad_sch]
2026-06-28 Day 13 -- IR leds, footprints
    [BOM.csv, schema.kicad_pcb, schema.kicad_sch]
2026-06-29 Day 14 -- whole schematics done with footprints
    [BOM.csv, schema.kicad_pcb, schema.kicad_sch]
2026-06-30 Day 14 -- PCB layout
    [schema-B_Cu.gbr, schema-B_Mask.gbr, schema-B_Paste.gbr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]
2026-07-02 Day 16 - PCB layout
    [schema.kicad_pcb, schema.kicad_sch]
2026-07-02 Day 17 - Started routing
    [schema.kicad_pcb, schema.kicad_sch]
2026-07-04 Day 17 - PCB 60% Done
    [schema.kicad_pcb]
2026-07-05 Day 19 - PCB done
    [schema-B_Cu.gbr, schema-B_Mask.gbr, schema-B_Paste.gbr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]
2026-07-08 Day 20 - Solved esp32 mis-pin alignment
    [schema.kicad_pcb, schema.kicad_sch]
2026-07-09 Day 21 - esp32 misalignment fixed
    [schema.kicad_pcb, schema.kicad_sch]
2026-07-10 Day 22 - fix: GND error, README
    [BOM.csv, Micromouse.stl, schema.kicad_pcb]
2026-07-14 Day 23: Added tactile button, boost conv
    [BOM.csv, schema.kicad_pcb, schema.kicad_sch]
2026-07-14 Day 24 -- Final commit on V1
    [BOM.csv, schema.kicad_pcb, schema.kicad_sch]
2026-07-14 Fix: README< BOM
    [BOM.csv]
2026-07-17 Fix: Organized Schematic folder
    [BOM.csv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]
2026-08-04 PCB quote changed
    [BOM.csv]
2026-08-23 Add: CAD design, motor mount, PCB corrections
    [BOM.csv, Final-CAD.stl, Motot_mount.stp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]
